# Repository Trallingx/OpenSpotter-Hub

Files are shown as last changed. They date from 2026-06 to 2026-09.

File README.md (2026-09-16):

# OpenSpotter Hub

OpenSpotter Hub is an open-source workspace for liquid-handling and spotting platforms. The repository currently contains one implemented platform, OpenSpotter-Syringe, together with its desktop control software, Klipper configuration, mechanical files, and engineering references.

## Platforms

- [OpenSpotter-Syringe](OpenSpotter-Syringe/README.md) is the active syringe-based spotting implementation.

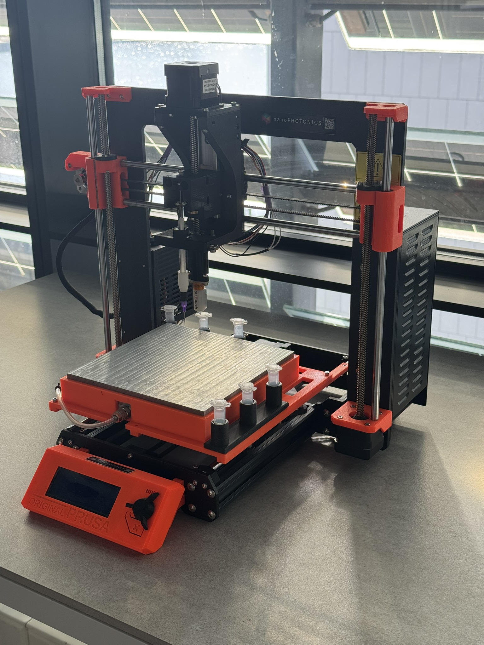
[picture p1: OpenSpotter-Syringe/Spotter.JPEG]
OpenSpotter-Syringe V1 hardware


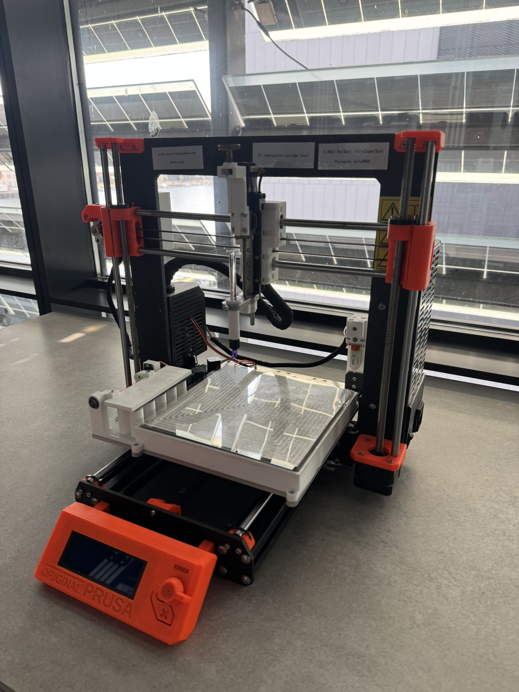
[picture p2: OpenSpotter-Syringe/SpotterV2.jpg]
OpenSpotter-Syringe V2 hardware


- [OpenSpotter-JetValve](OpenSpotter-JetValve/README.md) no JetValve implementation is present yet.

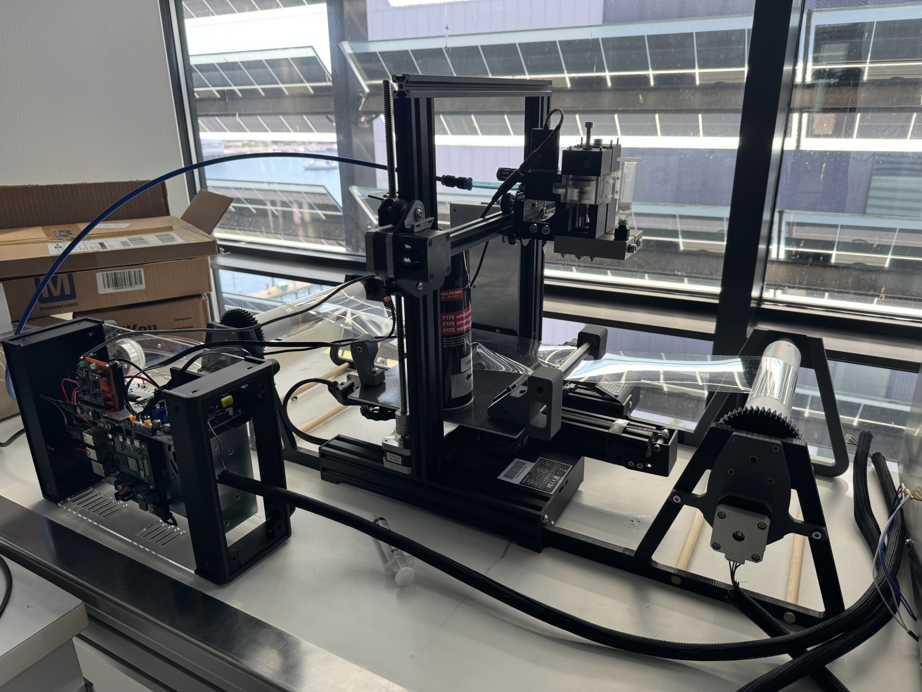
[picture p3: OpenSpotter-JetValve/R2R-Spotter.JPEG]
OpenSpotter-JetValve hardware


## Syringe project map

- [Getting started](OpenSpotter-Syringe/GETTING_STARTED.md)
- [Project scope](OpenSpotter-Syringe/PROJECT_DESCRIPTION.md)
- [Control application](OpenSpotter-Syringe/Spotter-Control_v3/README.md)
- [Klipper configuration](OpenSpotter-Syringe/Spotter-Control_v3/hardware/klipper/README.md)
- [CAD files](OpenSpotter-Syringe/CAD/README.md)
- [Engineering documents](OpenSpotter-Syringe/Docs/README.md)
- [Complete documentation index](OpenSpotter-Syringe/DOCS_INDEX.md)

## Safety and maturity

This is research hardware, not a validated medical or production system. Verify wiring, travel limits, tool state, calibration, generated G-code, and fluid compatibility on the physical machine before enabling motion or dispensing. The included Klipper configuration targets an Einsy RAMBo 1.1a and must be reviewed for the actual build.

The repository is licensed under the [MIT License](LICENSE.txt). Retain any additional file-level notices attached to adapted third-party material.

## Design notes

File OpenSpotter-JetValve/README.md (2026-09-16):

# Klipper OpenSource Spotter

Desktop GUI for drop-on-demand spotting with Klipper and Moonraker.

## Overview

Klipper OpenSource Spotter is a PyQt6 application that provides:
- valve control and macro execution
- 2D spotting canvas, live toolhead marker, and grid workflow
- status/logging and machine configuration panels
- Moonraker connectivity for motion and command execution

## Current Capabilities

- PyQt6 desktop UI with panels for machine status, controls, canvas, grid setup, valve config, and macro execution.
- Moonraker REST and WebSocket communication for connection status, G-code dispatch, subscribed toolhead position updates, and raw console responses.
- Top-bar Pi file editor for Moonraker-exposed config files and scripts, with save-to-Pi, save-and-restart, service status/actions, and a local Windows-to-Pi sync prompt for checked-in Pi-target files.
- Hardware-only spotting through the unified Klipper `SHOOT` macro; the current valve timing path preloads a Pi-connected Arduino over USB and triggers valve 0 or valve 1 with Pi host-MCU GPIO edges.
- Grid-based spotting with per-grid valve selection, per-grid speed, editable grid names, active/inactive grid toggles, and canvas redraws on grid changes.
- The canvas shows the latest toolhead position as a black X using the live gantry position signal.
- Roll-to-roll canvas mode renders two anchored rows per active grid and a compact row-progress legend instead of drawing every configured Y row.
- The spotting backend uses a row-indexed virtual spot sequence, windowed position projection, and bounded R2R progress payloads so large row counts do not allocate a full spot/path cache.
- Grid definitions are edited in the main window grid panel, not in the machine configuration dialog.
- Bounded spotting dispatch with editable Klipper send-ahead and refill-threshold settings, so a run tops the in-flight queue back up to the configured window after the configured number of spots completes.
- Active Stop and app shutdown are soft stops: the GUI stops refilling Klipper and clears pending local dispatch scripts without putting Klipper into shutdown.
- Configurable start and end G-code scripts stored in `config/machine_config.json`.
- User-facing actions and Moonraker traffic logged to `logs/dod_system.log`, trimmed in batches toward the newest 1000 lines so logging does not block high-rate spotting.

## Current Constraints

- Camera service and camera controller are placeholder-level.
- Calibration manager support is removed for now; only calibration data models remain.
- Test coverage is still limited, but includes model, macro command, spotting dispatch, and logging regressions.
- Hardware behavior should be validated against Moonraker/Klipper logs before changing motion or valve timing assumptions.

## Run

1. Create and activate a virtual environment.
2. Install dependencies.
3. Run the app.

```bash
pip install -r requirements.txt
python main.py
```

## Test

```bash
pytest tests/ -v
```

On the checked-in Windows development environment, use the virtualenv directly if `pytest` is not on PATH:

```powershell
.\.venv\Scripts\python.exe -m pytest tests/ -v
```

## Project Layout

- [models](models): data models
- [views](views): UI widgets and panels
- [controllers](controllers): orchestration and feature logic
- [services](services): Moonraker, camera, logging integrations
- [utils](utils): config, helpers, signals
- [docs](docs): hardware and integration documentation

## Documentation

- [DOCS_INDEX.md](DOCS_INDEX.md): documentation map
- [GETTING_STARTED.md](GETTING_STARTED.md): developer onboarding
- [PROJECT_DESCRIPTION.md](PROJECT_DESCRIPTION.md): concise project spec
- [AGENTS.md](AGENTS.md): mandatory Codex and contributor workflow rules
- [docs/START_TO_FINISH_FLOW.md](docs/START_TO_FINISH_FLOW.md): simple walk-through of the Start button to job completion
- [docs/PI_CR6_CONNECTION.md](docs/PI_CR6_CONNECTION.md): Pi + CR6 setup
- [docs/ARDUINO_VALVE_BRIDGE.md](docs/ARDUINO_VALVE_BRIDGE.md): Pi USB Arduino valve timing bridge
- [docs/TROUBLESHOOT_CONNECTION.md](docs/TROUBLESHOOT_CONNECTION.md): connection troubleshooting

## Contribution Rule

Read [AGENTS.md](AGENTS.md) before making changes. When behavior, architecture, commands, configuration, or setup steps change, update the relevant documentation and AGENTS change log in the same change.

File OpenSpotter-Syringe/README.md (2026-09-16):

# OpenSpotter-Syringe

OpenSpotter-Syringe is an open-source, syringe-driven liquid-handling and spotting platform. It combines a Python/Tkinter experiment editor, reproducible G-code generation, Klipper configuration for an Einsy RAMBo 1.1a, and two generations of mechanical design files.

SyringeSpotterV2 Hardware
OpenSpotter-Syringe hardware
GCODE creation GUI with Realtime Controls
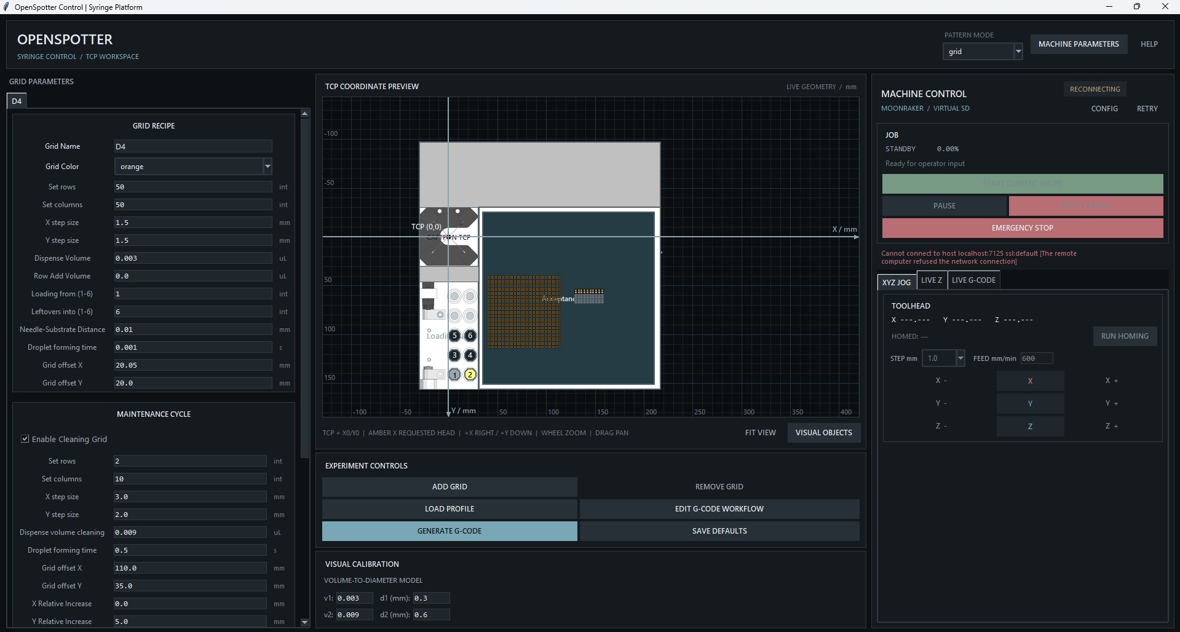
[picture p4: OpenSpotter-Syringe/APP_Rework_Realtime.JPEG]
OpenSpotter-Syringe hardware


# DEV NOTE
  The current capabilities (V2) are not 100% tested and a full test has not been run yet! The Spotter is not operational prior to software updates. The current version stops prior to bed meshing because of safety interlocks. This could be bypassed, but needs a proper check with test syringe (not glass !!!) before allowing moves. 

  The TCP finds the relative z position of the needle tip and the 3D-Touch creates a bed mesh to account for bed variations, but the offset between TCP-X-BEAM (trigger) and surface has not been measured yet. This will be a absolut offset that applies to all needles, even if mounted at different heights, but has to be manually checked once. RUN TCP calibration, RUN bed mesh, move needle to needle offset, move down to substrate (final accuracy z 20 micron), note offset. 

  Spiral mode is experimental and GCODE creation has not been veryfied. NOT operational!

## Current capabilities

- Configure multiple droplet grids, cleaning and washing cycles, final rinses, and spiral paths.
- Preview geometry in millimetres around the CAPTRON TCP beam crossing at X0/Y0.
- Edit Start, Loading, Printing, Cleaning, and End G-code event blocks at runtime.
- Save versioned JSON profiles beside generated G-code and load those profiles back into the application.
- Connect directly to Moonraker for exact virtual-SD upload/start, monitored Pause/Resume/Cancel, independent Emergency Stop, guarded XYZ motion, and live needle Z trim.
- Calibrate a needle TCP with the retained Klipper optical-cross module.
- Apply saved TCP offsets, bed mesh compensation, and a live needle-to-surface Z trim.
- Use a neutral graphite scientific UI defined centrally in `app/ui_theme.py`.

## Start here

- [GETTING_STARTED.md](GETTING_STARTED.md): install, validate, generate a job, and prepare hardware.
- [Spotter-Control_v3/README.md](Spotter-Control_v3/README.md): application behavior and profile contract.
- [Spotter-Control_v3/ARCHITECTURE.md](Spotter-Control_v3/ARCHITECTURE.md): deployable core/plugin architecture and dependency boundaries.
- [Spotter-Control_v3/PLUGIN_DEVELOPMENT.md](Spotter-Control_v3/PLUGIN_DEVELOPMENT.md): external pattern plugin contract and examples.
- [Spotter-Control_v3/DEPLOYMENT.md](Spotter-Control_v3/DEPLOYMENT.md): wheel, standalone, and writable-data deployment.
- [Spotter-Control_v3/hardware/klipper/README.md](Spotter-Control_v3/hardware/klipper/README.md): configuration, commissioning, TCP calibration, and movement safety.
- [CAD/README.md](CAD/README.md): mechanical-file inventory and manufacturing cautions.
- [Docs/README.md](Docs/README.md): BOM, schematics, datasheets, calibration references, and photos.
- [DOCS_INDEX.md](DOCS_INDEX.md): complete documentation map.

Generated files default to `Spotter-Control_v3/output/gcodes`. That directory is intentionally ignored except for `.gitkeep`; it contains runtime output, not maintained examples.

## Repository layout

- `Spotter-Control_v3/app/core`: reusable plugin, schema, storage, canvas,
  workflow, and shared G-code services.
- `Spotter-Control_v3/app/plugins`: built-in grid and spiral pattern packages;
  installed patterns use the documented entry-point contract.
- `Spotter-Control_v3/app`: generic desktop shell, compiled workflow renderer,
  direct-run artifacts, and Moonraker runtime/controller.
- `Spotter-Control_v3/config`: editable JSON defaults, workflow, visual layout, and UI state.
- `Spotter-Control_v3/hardware/klipper`: active Klipper configuration and custom TCP module.
- `Spotter-Control_v3/tests`: standard-library unit and integration tests.
- `CAD`: native design files and manufacturing exports.
- `Docs`: component and calibration references.

## Project status

Software generation and fake-Moonraker control paths have unit/integration coverage. Physical commissioning, hardware-in-the-loop validation, and experiment-specific risk assessment remain operator responsibilities. Computer vision, automatic lid handling, and a JetValve controller are not implemented in this repository.

Related publication: [ACS Sensors, DOI 10.1021/acssensors.5c02007](https://pubs.acs.org/doi/10.1021/acssensors.5c02007).

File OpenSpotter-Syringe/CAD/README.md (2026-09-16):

# OpenSpotter-Syringe CAD

The CAD directory contains two design generations:

- `Syringe_Spotter_V1`: 77 native `.prt` files.
- `Syringe_Spotter_V2`: 121 native `.prt` files plus selected manufacturing exports.

V2 exports include:

- `3D-Printing`: STL parts and one assembled 3MF package;
- `CNC-Mill`: machine-specific G-code exports;
- `Waterjetting`: DXF geometry with OMX, PDF, and log companions.

The folder names indicate design generations, not a formal released-build status. There is no authoritative release manifest identifying which duplicate or suffixed file is approved for a particular machine.

## Before manufacturing

1. Confirm the intended physical revision against the [BOM](../Docs/BOM.xlsx), drawings, and existing machine.
2. Open the native assembly and check dependencies, units, coordinate systems, clearances, and hardware.
3. Verify material, thickness, tolerances, orientation, and process parameters independently.
4. Regenerate CNC or waterjet toolpaths for the actual machine, stock, tooling, and controller. Checked-in G-code/OMX files are references, not universally safe jobs.
5. Inspect printable exports for scale, manifold geometry, supports, and fit before producing a full set.

For the TCP sensor and detachable-probe context, see the [engineering document index](../Docs/README.md) and [Klipper hardware guide](../Spotter-Control_v3/hardware/klipper/README.md).

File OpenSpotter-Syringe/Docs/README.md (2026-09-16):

# Engineering Documents

This directory collects component, electronics, and calibration references for OpenSpotter-Syringe. A file's presence does not prove that its revision matches every physical build; confirm part numbers, wiring, dimensions, and ratings before use.

## Build and electronics

- [Bill of materials](BOM.xlsx)
- [Einsy RAMBo 1.1a schematic](<Schematic Prints_Einsy Rambo_1.1a.PDF>)
- [LMD8S12BSS05-060 actuator datasheet](LMD8S12BSS05-060_Full_Datasheet.pdf)

The checked-in Klipper configuration targets the Einsy RAMBo 1.1a. Pin assignments and electrical limits still require comparison with the actual board and connected hardware.

## CAPTRON optical TCP

- [CAPTRON application note](CAPTRON_Application_Note_TCP.pdf)
- [CAPTRON optical-sensor catalog](CAPTRON-Optical-Sensors-Catalog.pdf)
- [OGLW2-40T-2PS6 datasheet](OGLW2-40T-2PS6-DS_V1.1_de_en.pdf)
- [OGLW2-70T4-2PS6 datasheet](OGLW2-70T4-2PS6-DS_V1.0_de_en.pdf)
- [TCP photo 1](TCP_1.jpg), [photo 2](TCP_2.jpg), [photo 3](TCP_3.jpg), [photo 4](TCP_4.jpg)

The active Klipper config names the OGLW2-40T-2PS6 and uses active-low NPN inputs. The 70T4 document remains a design/component reference.

## Calibration and coordinate stack

- [Needle, bed-mesh, TCP, and live-offset stack](needle-bed-mesh-tcp-offset-stack.pdf)
- [TCP calibration algorithm flow](../Spotter-Control_v3/hardware/klipper/config/scripts/tcp_calibration_flow.pdf)
- [Klipper commissioning guide](../Spotter-Control_v3/hardware/klipper/README.md)

## External references

- [Official Klipper documentation](https://www.klipper3d.org/)
- [Einsy RAMBo overview](https://reprap.org/wiki/EinsyRambo)
- [Einsy RAMBo development notes](https://reprap.org/wiki/EinsyRambo_development)

The repository's current host-side configuration is Moonraker/Mainsail-oriented. Use the checked-in configuration and hardware guide as the project source of truth.

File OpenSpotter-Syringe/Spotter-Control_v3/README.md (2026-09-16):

# Spotter-Control_v3

Spotter-Control_v3 is the local desktop recipe editor, G-code generator, and Moonraker machine console for OpenSpotter-Syringe. It uses Tkinter, Pillow, and a persistent aiohttp WebSocket/HTTP client. Saved-file generation remains available without a printer connection.

## Run

From this directory on Windows PowerShell:

```powershell
python -m venv .venv
.\.venv\Scripts\Activate.ps1
python -m pip install --upgrade pip
python -m pip install -e .
openspotter-control
```

On macOS or Linux:

```sh
python3 -m venv .venv
source .venv/bin/activate
python -m pip install --upgrade pip
python -m pip install -e .
openspotter-control
```

`python main.py` and `python -m app` remain equivalent source launchers. See
[DEPLOYMENT.md](DEPLOYMENT.md) for wheels, standalone builds, writable runtime
locations, and migration from an older checkout.

## Validate

```powershell
python -m pip install -e ".[test]"
python -m compileall -q app
python -m unittest discover -s tests -v
```

Launch the GUI after changes to appearance, interaction, paths, images, or workflow editing.

## Runtime logs

Each application run writes `openspotter-control.log` under the active runtime
root's `logs` directory. Source checkouts keep the historical local path;
installed and frozen builds use per-user writable storage. The file records
startup state, effective global and recipe options, workflow/profile changes,
generation choices, output paths, fallback defaults, and failures. Logs rotate
at 5 MB with five backups, and credential-like values are redacted.

The default level is `INFO`. Set `OPENSPOTTER_LOG_LEVEL=DEBUG` before launching to include detailed workflow-trigger decisions:

```powershell
$env:OPENSPOTTER_LOG_LEVEL = "DEBUG"
python main.py
```

## Interface

The interface uses a low-saturation graphite scientific palette, restrained steel-blue accents, semantic status colors, Segoe UI text, and Consolas for machine-oriented text. All shared colors, fonts, classic Tk options, and ttk styles live in `app/ui_theme.py`.

The main workspace provides:

- global machine parameters in a persistent maximized editor opened beside **HELP**;
- multiple grid recipes with optional cleaning, washing, and final-rinse behavior;
- multiple spiral recipes;
- a TCP-relative geometry preview;
- JSON profile loading;
- a runtime G-code workflow editor;
- atomic plugin-driven G-code generation (grid and spiral are built in);
- Moonraker connection state, virtual-SD Start/Pause/Resume/Cancel, HTTP emergency stop, guarded XYZ jog, an operator-owned `HOMING` action, live needle Z trim, and a read/queued G-code cursor.

## Persisted data

| Data | Location | Behavior |
| --- | --- | --- |
| Global and recipe defaults | `config/config_*.json` | Loaded at startup and updated through **SAVE DEFAULTS**. |
| Pattern counts | `config/config_states.json` | Schema-version 2 registered-plugin counts, with legacy built-in keys accepted. |
| Active workflow | `config/config_gcode_workflow.json` | Validated and saved explicitly in the workflow editor. |
| Preview objects and links | `config/config_visual_objects.json` | Saved independently; geometry never feeds the planner directly. |
| Moonraker example | `config/config_moonraker.example.json` | Key-free connection example. |
| Local Moonraker settings | `config/config_moonraker.json` | Created by **CONFIG**, ignored by Git, and may contain an API key. |
| Job snapshot | `*_settings.json` beside output | Reproducible schema-version 3 plugin profile with legacy built-in arrays. |

## Generate G-code

Select **GENERATE G-CODE** after adding at least one pattern recipe. The chosen path is a base path:

- every non-empty application plugin produces `<base>_<plugin-id>.gcode`;
- the built-in examples are `<base>_grid.gcode` and
  `<base>_spiral.gcode`;
- when several plugin workspaces contain recipes, each produces its own file;
- every G-code file receives a matching `<job>_settings.json` sidecar.

Profiles contain global settings, the recipes for that job type, derived runtime values, and the exact effective workflow. Writes are atomic. The dialog starts in `output/gcodes`; this directory is ignored runtime storage and contains no maintained examples.

**LOAD PROFILE** accepts JSON profiles only. Loading a profile:

1. validates the document structure;
2. replaces all registered pattern workspaces with the saved recipes;
3. restores global values;
4. if `workflow` is present, validates it and overwrites the active `config/config_gcode_workflow.json`.

Treat profile loading as a workflow change, not only a form import.

## Direct Moonraker control

The right-side machine panel starts a background Moonraker runtime without blocking Tk. **CONFIG** edits the host, port, protocol, route prefix, and optional API key; **RETRY** restarts monitoring. The WebSocket is persistent, identified as a desktop client, and subscribes to printer, virtual-SD, position, prompt, saved calibration, and live-Z state. Commands queued before connection or lost before sending fail instead of replaying after reconnect. On a Pi Zero, a fixed IPv4 address can avoid Windows `.local`/mDNS lookup delays.

Deploy the current `hardware/klipper/config/hardware.cfg`, `remote_control.cfg`, and `movement_safety.cfg` together, keep the current `config/config_gcode_workflow.json`, preserve the operator-owned Klipper configuration that defines `HOMING`, and restart Klipper. The app checks Klipper's advertised commands for the immutable `OPENSPOTTER_CONTRACT_V4` marker and the single required homing macro `HOMING`. Start, Home, jog, and related machine controls remain disabled when that contract is missing or stale.

**START CURRENT RECIPE** follows this contract:

1. require locked machine parameters and a connected, ready, idle Klippy state;
2. ask the selected plugin to capture immutable recipes on the Tk thread;
3. reject invalid text, unbounded pattern/maintenance work, or non-finite inputs;
4. generate and hash the exact artifact in a worker, using compiled workflow expressions;
5. compare rendered XYZ targets plus saved TCP/live-Z offsets with live axis limits;
6. require a loaded BLTouch when the artifact uses `MESH`, and valid TCP coordinate version 2 when it enables needle offsets;
7. show the artifact hash, workflow hash, size, line count, destination, and physical-action warning for final operator confirmation;
8. upload with `print=false`, run a fresh ready/idle preflight, and send one `printer.print.start` RPC.

The separate upload/start sequence deliberately avoids Moonraker’s optional upload queue, which could otherwise schedule motion for later. Repeated identical artifacts use the same SHA-256 remote filename under `gcodes/openspotter/<kind>/`; local runtime output retains the newest 20 artifacts per kind.

Pause/Resume and Stop control the active virtual-SD job. Stop invokes Klipper cancellation and the non-motion `OPENSPOTTER_JOB_CLEANUP` macro. **EMERGENCY STOP** bypasses the WebSocket command queue and posts directly to Moonraker’s authenticated `/printer/emergency_stop` endpoint with a short timeout.

XYZ jog is available only while connected, ready, idle, inactive in virtual SD, and homed on all axes, with needle offsets disabled and bed mesh cleared. It calls the reviewed `OPENSPOTTER_JOG` firmware macro, which requires at least 30 mm/min and validates finite distance/feed values, axis-specific limits, physical toolhead bounds, and movement dead zones.

The UI Home action issues exactly one bare `HOMING` command, and the default workflow also contains exactly one bare `HOMING` command. The application does not define or inspect that macro's physical choreography. Define and commission it in operator-owned Klipper configuration outside `remote_control.cfg`.

The V4 interface requires `HOMING` to be safe both when called from the idle UI and when called at the start of an active virtual-SD job. Before its first move it must either neutralize needle offsets and bed mesh or reject the call, it must preserve and restore relevant modal G-code state, and it must return with XYZ homed. Make `M400` its final executable command so all queued physical motion completes before the macro returns. `HOMING` is public to every authorized Moonraker client, so the firmware macro itself—not only this application's UI checks—must validate its preconditions.

When a job artifact uses `MESH`, Start preflight already requires the saved BLTouch state to be `loaded`; the operator must also verify the tool physically before Start. `HOMING` is not relied upon to load or park the BLTouch.

Live Z calls the transactional needle-offset macros only during an active job while offsets are enabled. Negative values move closer to the substrate; positive values move away. UI adjustments are live (`SAVE=0`) and are not persisted automatically.

The canvas adds an amber **LIVE REQUESTED TOOLHEAD** cross when Moonraker has supplied fresh position data for homed X/Y axes. It shows Klipper's requested trajectory in raw carriage coordinates rather than encoder feedback, and is intentionally separate from the logical needle-tip path when TCP offsets are enabled. The marker is hidden on disconnect, Klippy restart, stale telemetry, or unhomed X/Y, and it follows pan/zoom without refitting the workspace.

The G-code tab shows Moonraker’s `virtual_sdcard.file_position` mapped onto the exact local artifact. It is explicitly a virtual-SD read/queued cursor, not proof that physical motion has completed. The view is hidden if another filename is active. A response timeout or post-send disconnect is treated as an unknown printer-side outcome; normal controls remain interlocked until monitoring is reconnected, while Emergency Stop stays available.

**MANUAL / CONSOLE** parses text before it can be sent. It accepts a small diagnostic allowlist plus `G90`, `G91`, and bounded `G0`/`G1` XYZ/F moves. Raw motion requires an explicit coordinate mode and feed in the same script, Klipper-native plain decimal words (no `=` or scientific notation), live bounds, homed XYZ, offsets and bed mesh off, no virtual-SD activity, a 30–6000 mm/min feed, and an estimated total duration no longer than 60 seconds. The operator-owned `HOMING` macro is accepted only as a standalone action; unknown macros, raw `G28` homing, arcs, output/driver changes, safety mutations, and other bypass commands are blocked. `M112`/`EMERGENCY_STOP` is routed through Moonraker's HTTP emergency-stop endpoint rather than the queued G-code path. A partial script error, missing completion sentinel, E-stop, timeout, or disconnect latches the machine controls until the operator inspects the printer and reconnects monitoring.

Preflight is not a complete interpreter for arbitrary custom macros or raw G-code. Review the exact artifact and perform an elevated, fluid-free dry run after changing workflows, profiles, fixtures, or firmware. The supplied Moonraker configuration permits unauthenticated clients from IPv4 private and link-local networks so any local PC can use Mainsail or OpenSpotter; keep port 7125 off the public Internet.

## Runtime G-code workflow

**EDIT G-CODE WORKFLOW** opens the editor for ordered Start, Loading, Printing, Cleaning, and End blocks. Sections attach templates and optional conditions to planner events. The editor supports validation, rendered previews, searchable scoped variables, and custom-variable expressions.

The editor opens maximized in normal windowed mode. Its workspace and preview area share a vertical page scrollbar, while the header, status, and Save/Cancel controls remain visible.

The Python planner retains numeric state and the physical lifecycle: start, refill, pattern motion, maintenance, emptying, and end. Workflow blocks are event hooks; reordering them changes template order for a matching event but does not replace the planner.

Variables are namespaced by global, grid, cleaning, washing, spiral, container, runtime, or custom scope. Grid-only and spiral-only values on shared events should be guarded with a condition such as `runtime.job.kind == 'grid'`. `custom.syringe_mm_per_ul` and `custom.spiral_resolution_radians` are required planner inputs and must remain positive.

Grid and spiral are the shipped pattern plugins. Compatible installed plugins
may add workspaces, workflow events, canvas previews, saved generation, and
direct-run capture/generation through plugin API 1. Startup needle calibration
and hardware TCP calibration remain separate safety workflows.

## TCP coordinate preview

The CAPTRON beam crossing is visual X0/Y0. Positive X is right and positive Y is down, matching the configured machine motion from the TCP toward the work area. Scroll zooms, dragging pans, and **FIT VIEW** restores the useful extent.

**VISUAL OBJECTS** manages rectangles, circles, and images:

- rectangle X/Y identifies its top-left corner;
- circle X/Y identifies its centre;
- image X/Y identifies its top-left corner;
- width and height may differ, producing an oval;
- images are stretched to the exact width and height entered in millimetres;
- **IMPORT IMAGE…** starts in the project asset folder and can browse to any image path; select **APPLY CHANGES** to persist the draft;
- project-contained images are stored with portable relative paths, while external files use absolute paths;
- text size, descriptive text, and color are editable; image color controls its centred description text;
- rectangle and circle fills are solid;
- X, Y, width, and height can each be linked to a numeric program input by using the dropdown beside the value;
- the object list is a layer stack: higher rows draw above lower rows, and **MOVE UP** / **MOVE DOWN** persist adjacent layer changes immediately.

The program input is authoritative while a property is linked. Changing that input moves or resizes every linked object on the next canvas refresh. Changing a linked value in **VISUAL OBJECTS** and selecting **APPLY CHANGES** writes the value back to the program input, so every other object using the same link follows it. Locked global machine parameters cannot be changed through the visual editor; unlock them through the normal safety control first. Visual links are saved immediately, while changed program values use the existing **SAVE DEFAULTS** action for persistence.

The editable layout starts with the former canvas overlays: build plate, acceptance area, six containers, and the CAPTRON TCP image. Legacy container circles automatically link X/Y to `global.containerN_x/y`, including existing schema-version 1 layouts, so the visual container and loading coordinate remain coupled. Other stable choices include indexed grid, cleaning, washing, and spiral inputs such as `grid.1.grid_offset_x`. The CAPTRON object uses `assets/Captron-TCP.png` and defaults to exactly 60 × 60 mm at X=-30..30 and Y=-30..30.

Unlinked object values remain annotations and never enter generated commands, homing, firmware limits, acceptance checks, or Klipper configuration. A linked visual edit can affect generation only by updating its real program input; visual-object geometry itself is still excluded from the planner. Missing or temporarily invalid link sources use the object's stored fallback value. The coordinate grid, TCP origin marker, generated grid/spiral points, cleaning previews, and washing lines remain live preview primitives rather than editable layout objects. The preview and its acceptance warning are planning aids, not collision protection.

## Hardware boundary

The supplied application workflow disables needle offsets before `HOMING` and `MESH`, then enables them after `MESH`, and disables them at job end. When enabled, the Klipper wrapper applies:

```text
machine X = commanded X + tcp_offset_x
machine Y = commanded Y + tcp_offset_y
machine Z = commanded Z + tcp_offset_z + needle_surface_z_offset
```

Relative moves remain deltas and Klipper bed mesh remains active independently. This behavior is editable through the workflow, so inspect the effective profile rather than assuming the shipped defaults.

TCP calibration now records coordinate version 2. Saved offsets from the former positive-up Y convention are rejected until calibration is run again.

The workflow does not run `TCPSTART` and does not automatically load or park the detachable BLTouch. Direct Start checks the saved readiness state but cannot verify physical tool attachment. Deploy the complete matching hardware/remote-control/safety configuration, restart Klipper, and follow the [Klipper hardware guide](hardware/klipper/README.md) before any machine run.

## Layout

- `main.py`: stable launcher.
- `app/core`: reusable contracts and services for plugins, schemas, storage,
  canvas previews, workflow composition, and shared G-code lifecycle.
- `app/plugins`: built-in grid and spiral pattern packages.
- `app`: generic Tk shell, compiled workflow renderer, runtime artifacts, and
  Moonraker runtime/controller.
- `config`: defaults and persisted application state.
- `assets/images`: current static GUI images.
- `tests`: planner, workflow, generation, visual-object, and hardware-config checks.
- `hardware/klipper`: active printer configuration and custom TCP module.
- `output/gcodes`: ignored runtime output.
- [DEPLOYMENT.md](DEPLOYMENT.md): source, wheel, standalone, and runtime-data deployment.
- [VERSIONING.md](VERSIONING.md): application, schema, and firmware compatibility versions.
- [CHANGELOG.md](CHANGELOG.md): user-visible release history.
- [ARCHITECTURE.md](ARCHITECTURE.md): core/plugin boundaries, runtime layers,
  dependency rules, and migration status.
- [PLUGIN_DEVELOPMENT.md](PLUGIN_DEVELOPMENT.md): installed entry points and
  desktop plugin hooks.
- [Spotter_Control_Dev.md](Spotter_Control_Dev.md): source-level developer map.

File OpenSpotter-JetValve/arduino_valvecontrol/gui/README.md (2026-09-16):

# Arduino Timing GUI

PyQt5 desktop app to control the ON/OFF timings on the Arduino via the serial protocol implemented in `main.cpp`.

## Setup

1. Install Python 3.10+.
2. In this folder, install deps:
   ```bash
   pip install -r requirements.txt
   ```
3. Run the app:
   ```bash
   python app.py
   ```

## Firmware protocol (implemented in main.cpp)
- `?` or `W` — request current state.
- `S:onMin:onMax:offMin:offMax` — set ranges; step ≈ (max-min)/9.
- `O:<ms>` — set ON time directly.
- `P:<ms>` — set OFF time directly.
- `E` / `R` — ON minus/plus one step.
- `D` / `F` — OFF minus/plus one step.
- `T` — toggle run/stop (output forced LOW when stopped).
- State line format: `STATE on=<ms> off=<ms> onRange=<lo>-<hi> offRange=<lo>-<hi> running=0|1`.

## GUI controls
- Port selector → Connect.
- Checkbox "Running" toggles `T`.
- ON row: min/max fields, slider, value label, buttons "ON - (E)" / "ON + (R)" (keyboard E/R).
- OFF row: same pattern with D/F.
- Sliders and buttons snap to the step implied by current ranges.

## Notes
- The app polls serial every 50 ms and debounces slider/range changes.
- If the port drops, the app will disconnect and show an error in the status label.

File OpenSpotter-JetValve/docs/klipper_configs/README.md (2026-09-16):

# Klipper Config Snippets

Reusable Pi/CR6 snippets for the current GUI integration.

## Files

- `printer.cfg`: top-level include template
- `steppers.cfg`: CR6 axes plus `r2r_rewind` manual stepper helpers
- `valve_macros.cfg`: Arduino bridge, valve timing preload, and `SHOOT`
- `moonraker.conf`: Moonraker sample
- `mainsail.cfg`: Mainsail macro sample
- `sonar.conf`: optional network watchdog sample

Legacy LED and safety snippets were removed; keep new setup steps aligned with the files listed above.

## Valve Path

- Continuous spotting uses `SET_ARDUINO_VALVE_TIMING` once per active valve, then per-spot `SHOOT ... TRIGGER_MODE=mcu`.
- Current Arduino firmware is pulse-only. `HOLD`, latched `VALVE_ON`, and latched `VALVE_OFF` are unsupported.
- MCU-mode per-spot `SHOOT` omits `ON_MS`, `OFF_MS`, and `CYCLES`; those values come from the preload.
- USB fallback can still send `ON_MS`, `OFF_MS`, and `CYCLES` for manual testing.

## Start And End G-code

The GUI stores free-form scripts in `config/machine_config.json`:

- `klipper.start_gcode`: runs before spotting homing validation.
- `klipper.end_gcode`: runs after spotting finishes or stops.
- `klipper.connect_gcode`: runs once after Moonraker connects.

Enter one G-code command per line. Blank lines are ignored.

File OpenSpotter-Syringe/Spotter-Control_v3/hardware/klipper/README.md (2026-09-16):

# OpenSpotter Klipper Configuration

This directory contains the active Klipper configuration template for the OpenSpotter-Syringe build. It targets an Einsy RAMBo 1.1a with TMC2130 drivers, a manual syringe stepper, a detachable BLTouch-compatible probe, and a CAPTRON optical TCP cross.

It is not a universal or automatically safe configuration. Pins, axis directions, sensorless-homing thresholds, travel limits, dock coordinates, optical geometry, and syringe direction must be verified on the physical machine.

## Active files

`config/printer.cfg` is the include root:

| File | Responsibility |
| --- | --- |
| `hardware.cfg` | X/Y/Z pins, ranges, homing, and servo |
| `tmc2130.cfg` | All X/Y/Z/syringe TMC2130 sections |
| `syringe.cfg` | Manual syringe stepper and dispense/aspirate macros |
| `bltouch.cfg` | Probe pins, detachable dock macros, and saved-state initializer |
| `movement_safety.cfg` | G0/G1 wrappers, TCP/live-Z offsets, and persistent dead zones |
| `bed_mesh.cfg` | Bed mesh and `MESH`, `MESH_LOAD`, `MESH_CLEAR` macros |
| `display.cfg` | 20 × 4 LCD content |
| `mainsail.cfg` | Minimal virtual-SD, pause, resume, cancel, display, and respond support |
| `remote_control.cfg` | Guarded desktop jog support, contract marker, structured prompts, and job cleanup |
| `tcp_calibration.cfg` | Optical sensor power, macros, pins, and module settings |

`config/moonraker.conf` configures the separate Moonraker service and is not included by Klipper. `config/saved_vars.cfg` is a repository seed with only the initial syringe position; calibration and runtime values are machine-specific.

The repository does not vendor Klipper. The canonical custom module is `config/scripts/tcp_calibration.py`.

## Deployment

Back up the printer's existing configuration and Klipper source before replacing anything.

1. Copy the contents of `config` into the printer's configuration directory, normally `~/printer_data/config`.
2. Install the custom TCP module as described in [config/scripts/README.md](config/scripts/README.md).
3. Review the MCU serial path in `printer.cfg`, the virtual-SD path in `mainsail.cfg`, and any Moonraker paths for the actual host.
4. Compare every pin and connector with the supplied [Einsy RAMBo 1.1a schematic](../../../Docs/Schematic%20Prints_Einsy%20Rambo_1.1a.PDF).
5. Restart Klipper and resolve configuration errors before energizing motion.
6. Commission one subsystem at a time with the tool clear, low current/speed where practical, and an accessible emergency stop.

Do not deploy `remote_control.cfg` alone. At minimum, copy the current `hardware.cfg`, `movement_safety.cfg`, and `remote_control.cfg` together, keep the desktop's current `config/config_gcode_workflow.json`, preserve the operator-owned configuration that defines `HOMING`, and restart Klipper before using Start, jog, Home, prompt, or cleanup controls. The desktop requires the immutable `OPENSPOTTER_CONTRACT_V4` marker and the `HOMING` command; machine controls remain disabled if Klipper advertises a missing or stale contract.

In the desktop **CONFIG** window, enter the Moonraker host, port, protocol, optional route prefix, and API key. Local `config/config_moonraker.json` is ignored by Git; keep credentials out of the key-free example. A fixed IPv4 address may connect more quickly and reliably than `.local` on a Pi Zero/Windows mDNS combination.

The shipped `moonraker.conf` trusts localhost plus all IPv4 private and link-local client ranges, allowing Mainsail and OpenSpotter to connect from any PC on the local/private network without an API key. Public Internet addresses are not trusted. Keep the printer network isolated and do not expose TCP port 7125 through router port forwarding.

Do not copy calibrated `saved_vars.cfg` values from another machine.

## Commissioning checks

Before a job:

- confirm X/Z direction, and confirm positive Y moves from the TCP toward the work area (down in the top view);
- commission the operator-owned `HOMING` macro in both idle and active virtual-SD job-start contexts with fixtures and tools clear, verify each axis/endstop behavior at reduced risk, and make `M400` its final executable command;
- verify the syringe endstop, plunger direction, and volume conversion without fluid;
- verify BLTouch pin behavior and dock coordinates at reduced risk;
- test TCP power and both beam inputs;
- calibrate TCP and inspect the saved offsets;
- define and test fixture dead zones;
- confirm `OPENSPOTTER_CONTRACT_V4`, `HOMING`, `OPENSPOTTER_JOG`, `OPENSPOTTER_RUNTIME_STATUS`, and `NEEDLE_TIP_OFFSETS_STATUS` are recognized;
- confirm Moonraker exposes live toolhead limits, saved variables, the OpenSpotter runtime macro, and the needle-offset macro;
- run elevated, fluid-free G-code while watching machine coordinates.

The syringe coordinate model is E=0 at empty/fully depressed and E=50 mm at homed/full. `ASPIRATE` increases position toward 50; `DISPENSE` decreases it toward 0. Normal macro motion is clamped to that 0–50 mm working range, while the manual stepper's 70 mm `position_max` provides homing overtravel. Verify the real plunger direction, endstop location, and volume conversion before dispensing.

## Detachable BLTouch state

`LOAD_BLTOUCH` and `PARK_BLTOUCH` reject moves unless the saved state permits the requested transition. On a new `saved_vars.cfg`, state is unknown.

Physically inspect the probe first, then initialize the record:

```gcode
SET_BLTOUCH_DOCK_STATE STATE=parked
```

or:

```gcode
SET_BLTOUCH_DOCK_STATE STATE=loaded
```

This command does not move hardware. Use it only after physical verification. `TCPQUERYBLTOUCH` reports the state used by TCP guards.

The dock macros use raw `G0.1` moves so needle offsets are not applied. Those raw moves also bypass the normal G0 safety wrapper; verify dock coordinates and a clear path before use.

## Optical TCP calibration

The active-low NPN inputs are X on `PH0` and Y on `PK0`; sensor power is switched on `PE5`. The Python extra uses continuous homing-style moves rather than polling.

The active coordinate convention is positive X right and positive Y down in the machine top view. The reflected beam normals and `Y_DIRECTION=-1` keep the TCP scan on the same physical beam paths after the Y stepper direction inversion. Any machine calibrated under the previous Y convention must be homing-tested and TCP-calibrated again before saved needle offsets are enabled.

Calibration requires:

- all XYZ axes homed;
- saved BLTouch state `parked`;
- TCP power recorded on;
- a clear start position on the right/X+ side of the optical cross.

Test the inputs before motion:

```gcode
TCPON
TCPQUERYBEAMS
TCPOFF
```

With power on, query once clear and once while interrupting each beam by hand. `PRESSED` means that beam is disrupted.

For the normal guarded sequence, first disable needle corrections, run the commissioned `HOMING` macro, verify that it completed, and then run:

```gcode
TCPSTART X=<clear_start_x> Y=<clear_start_y> Z=<clear_start_z> HEIGHT=<beam_height> CALX=<nominal_cross_x> CALY=<nominal_cross_y> CALZ=<nominal_tip_z>
```

`X/Y/Z` position the clear start. `CALX/CALY/CALZ` are the expected final coordinates used to calculate offsets; if omitted they default to X/Y/Z. `TCPSTART` raises to `LIFTZ`, positions the tool, powers the sensor, calls the calibration module, then powers it off.

The module:

1. acquires the X beam with a pure-X move;
2. centres and follows that beam upward to the needle tip edge;
3. re-centres X at `tip_z - 2 mm`;
4. follows the physical X beam to centre Y in the same plane;
5. accepts the result only if stationary X and Y queries both report `PRESSED`.

Success saves `tcp_tip_x/y/z`, `tcp_offset_x/y/z`, `tcp_coordinate_version=2`, and `tcp_ready=True`. Needle-offset motion rejects older or unversioned calibrations. Inspect them with:

```gcode
TCPSHOWOFFSETS
NEEDLE_TIP_OFFSETS_STATUS
```

On a calibration fault, assume the TCP output may still need explicit cleanup and run `TCPABORT`; use `TCPABORT EMERGENCY=1` only when an emergency shutdown is required. The [TCP calibration flow diagram](config/scripts/tcp_calibration_flow.pdf) documents the routine.

## Needle offsets and bed mesh

Normal `G0` and `G1` are wrapped. With needle offsets enabled, absolute targets become:

```text
X machine target = X command + tcp_offset_x
Y machine target = Y command + tcp_offset_y
Z machine target = Z command + tcp_offset_z + needle_surface_z_offset
```

Relative moves remain unmodified deltas. Klipper applies the active bed mesh separately after the corrected target is sent.

Common commands:

```gcode
NEEDLE_TIP_OFFSETS_ENABLE
NEEDLE_TIP_OFFSETS_DISABLE
NEEDLE_TIP_OFFSETS_STATUS
SET_NEEDLE_SURFACE_OFFSET Z=-0.030 MOVE=1 SAVE=1
ADJUST_NEEDLE_SURFACE_OFFSET Z_ADJUST=0.005 MOVE=1
RESET_NEEDLE_SURFACE_OFFSET MOVE=1 SAVE=1
```

Enabling requires `tcp_ready=True` by default. `REQUIRE_TCP=0` exists for a controlled dry run and must not be used to imply a valid calibration.

The live surface trim defaults to a permitted range of -2 to +2 mm. Negative moves the needle closer to the substrate; positive moves it higher. `MOVE=1` applies the delta physically only while offsets are enabled, and `SAVE=1` persists it.

The shipped application workflow disables offsets before `HOMING` and `MESH`, enables them afterward, and disables them at job end. The workflow is editable and profiles embed the effective copy, so verify each job.

The application workflow does not call `TCPSTART` and does not automatically load or park the BLTouch. It assumes calibration and tool state have been prepared by the operator. Start preflight requires saved BLTouch state `loaded` before accepting an artifact that uses `MESH`, and the operator must verify the tool physically before Start; `HOMING` is not relied upon to load or park it.

The desktop direct-run preflight blocks an artifact containing `MESH` unless saved BLTouch state is `loaded`, and blocks needle-offset enablement unless `tcp_ready=True` with coordinate version 2. These are saved-state checks, not physical sensors: inspect the detachable tool and work area yourself.

Artifact preflight is deliberately conservative, but it is not a full Klipper G-code/macro interpreter. It checks rendered direct XYZ targets, current offsets, required saved tool state, and bounded work; custom workflow/profile commands may have additional effects. Review the exact confirmed artifact and run an elevated, fluid-free dry run after workflow, profile, fixture, or firmware changes.

## Desktop remote-control contract

The desktop uses the application-owned support commands below plus one operator-owned homing command:

```gcode
HOMING
OPENSPOTTER_JOG AXIS=X DISTANCE=1 F=600
OPENSPOTTER_RUNTIME_STATUS
OPENSPOTTER_JOB_CLEANUP
```

The UI Home action issues exactly one bare `HOMING` command, and the default workflow also contains exactly one bare `HOMING` command. `remote_control.cfg` intentionally does not define `HOMING`, and the application does not inspect or add to its physical choreography. Define and commission the macro in operator-owned Klipper configuration and keep that file outside `remote_control.cfg`.

The V4 interface requires `HOMING` to be safe in both supported call contexts: an idle UI request and the start of an already-active virtual-SD job. Before its first move the macro must neutralize needle offsets and bed mesh or reject the call, preserve and restore relevant modal G-code state, return with XYZ homed, and use `M400` as its final executable command. Because other authorized Moonraker clients can invoke the public macro without the OpenSpotter UI interlocks, `HOMING` itself must validate every precondition on which its safe execution depends.

`OPENSPOTTER_JOG` requires Klippy idle, inactive virtual SD, all XYZ axes homed, needle offsets disabled, and bed mesh cleared. It rejects non-finite/zero distance, limits XY to 25 mm and Z to 5 mm per command, requires at least 30 mm/min, caps XY feed at 6000 mm/min and Z feed at 1500 mm/min, checks live physical toolhead limits, and runs the dead-zone guard.

`OPENSPOTTER_JOB_CLEANUP` performs no motion. It disables needle offsets, clears bed-mesh compensation, clears the structured prompt/LCD message, and is called by normal completion, cancellation, and virtual-SD error handling.

The live needle-Z setter validates finite range/feed and the physical target, runs movement safety before changing coordinate mode, performs the compensation move, restores state, and only then commits or persists the new offset. Desktop adjustments use `SAVE=0`.

Desktop Emergency Stop bypasses the G-code/WebSocket command queue and sends a short-timeout authenticated HTTP POST directly to Moonraker `/printer/emergency_stop`.

The desktop manual console is intentionally not a general Klipper terminal. It permits a small diagnostic-query allowlist and bounded `G90`/`G91` plus `G0`/`G1` XYZ/F tests with explicit mode/feed, live bounds, homed XYZ, offsets/mesh off, no virtual-SD activity, and a 60-second estimated cap. The operator-owned `HOMING` macro is accepted only as a standalone action; unknown macros and commands that bypass homing, movement safety, offsets, drivers, outputs, or job preflight are blocked. Manual `M112` is routed to the same HTTP Emergency Stop. Partial execution errors or a missing completion response latch controls until the machine is inspected and monitoring is reconnected.

## Dead-zone guard

Movement safety is disabled by default unless a saved state enables it. Zones are persistent XY rectangles with a Z clearance and independent allowances for travel above the fixture, exit, pure Z lift/lower, or XY motion inside. The guard conservatively treats a move's XY bounding box as its swept area.

```gcode
SET_DEAD_ZONE NAME=fixture X_MIN=80 X_MAX=170 Y_MIN=60 Y_MAX=160 Z_CLEARANCE=20 ALLOW_WHEN_ABOVE=1 ALLOW_EXIT=1 ALLOW_Z_LIFT=1
MOVEMENT_SAFETY_ENABLE
MOVEMENT_SAFETY_STATUS
REMOVE_DEAD_ZONE NAME=fixture
CLEAR_DEAD_ZONES
```

Test every zone with controlled moves. `G0.1` and `G1.1` are the renamed raw Klipper moves; they bypass both correction and the normal guard and should remain limited to reviewed machine macros.

## References

- [Engineering document index](../../../Docs/README.md)
- [Needle, bed-mesh, TCP, and live-offset stack](../../../Docs/needle-bed-mesh-tcp-offset-stack.pdf)
- [Custom TCP module](config/scripts/README.md)
- [Official Klipper documentation](https://www.klipper3d.org/)
- [Official Moonraker file API](https://moonraker.readthedocs.io/en/latest/external_api/file_manager/)
- [Official Moonraker printer API](https://moonraker.readthedocs.io/en/latest/external_api/printer/)

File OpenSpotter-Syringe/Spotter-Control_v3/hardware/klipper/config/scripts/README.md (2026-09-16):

# Klipper Custom Scripts

`tcp_calibration.py` is a Klipper `extras` module for continuous optical-cross
TCP calibration.

The routine performs one pure-X acquisition, then centers X with diagonal
sweeps normal to the X beam while following the needle upward to its tip edge.
At `tip_z - 2 mm`, it re-centers X, follows the physical X beam to cross and
center Y, solves both beam coordinates in that common Z plane, and accepts the
result only when stationary sequential queries report both beams `PRESSED`.
The fixture convention is a clear start on the right/X+ side: acquisition moves
X-, the X beam rises toward X-, and the Y beam rises toward X+.

For this workspace it is installed here:

```text
../klipper-master/klippy/extras/tcp_calibration.py
```

From this `scripts` folder, refresh that workspace copy with:

```powershell
Copy-Item -LiteralPath .\tcp_calibration.py -Destination ..\klipper-master\klippy\extras\tcp_calibration.py -Force
```

Remove the workspace copy with:

```powershell
Remove-Item -LiteralPath ..\klipper-master\klippy\extras\tcp_calibration.py
```

For a printer deployment, copy the same file to the active Klipper source tree:

```sh
cp ~/printer_data/config/scripts/tcp_calibration.py ~/klipper/klippy/extras/tcp_calibration.py
sudo systemctl restart klipper
```

Remove the printer deployment with:

```sh
rm ~/klipper/klippy/extras/tcp_calibration.py
sudo systemctl restart klipper
```

Then include `tcp_calibration.cfg` when installed, or remove that include when
the Python module has been removed.

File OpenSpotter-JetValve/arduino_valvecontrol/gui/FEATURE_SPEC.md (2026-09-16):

# Spotter Solenoid Control - Feature Specification

## Purpose
Desktop UI owns all settings and sends pulse commands to an Arduino-controlled solenoid output.
The Arduino only executes pulses and reports errors or pulse-activation messages.

## Architecture
- GUI: PyQt5 app in `app.py`
- Serial transport: `serial_client.py`
- Firmware protocol: `src/main.cpp`

## Serial Protocol
- `S:onMin:onMax:offMin:offMax`: set timing ranges
- `O:<ms>`: set ON time directly
- `P:<ms>`: set OFF time directly
- `E` / `R`: ON minus/plus one step
- `D` / `F`: OFF minus/plus one step
- `K:<count>`: trigger a burst of `count` cycles using the current ON/OFF values

## Firmware Responses
- `ERR ...`: invalid command or invalid parameter
- `ACT pulse=<n> phase=HIGH|LOW`: pulse activation updates

## UI Functional Requirements
- Auto-detect/select the most likely COM port.
- Connect/disconnect serial session.
- Show status text for connection and protocol errors.
- Show and control:
  - ON min/max, slider, current value label
  - OFF min/max, slider, current value label
  - cycle count
- Keyboard shortcuts:
  - `E`/`R` for ON down/up
  - `D`/`F` for OFF down/up
  - `K` for sending pulses
- Keep sliders clamped to current range.
- Prevent invalid range send (`min >= max`).
- Prevent transient typing values from being transmitted (example: typing 900 should not send 9).

## Behavioral Rules
- The GUI is authoritative for settings.
- The Arduino must not overwrite UI state with a separate state model.
- On connect:
  - open port
  - allow command entry
- On disconnect/read failure:
  - close serial
  - stop timers
  - show disconnected state
- On range change:
  - commit text edits first
  - validate ranges
  - sync sliders
  - send range plus current values
- On shot:
  - commit edits
  - validate ranges
  - push current range plus current values
  - send burst command

## Non-Goals
- No running mode.
- No persistent device state synchronization.
- No plotting/history views.

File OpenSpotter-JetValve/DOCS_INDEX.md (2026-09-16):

# Documentation Index

This project keeps a compact, task-focused documentation set.

## Start Here

1. [README.md](README.md)
Purpose: run the app and get high-level context.

2. [GETTING_STARTED.md](GETTING_STARTED.md)
Purpose: practical contributor workflow.

3. [PROJECT_DESCRIPTION.md](PROJECT_DESCRIPTION.md)
Purpose: architecture and project scope.

4. [AGENTS.md](AGENTS.md)
Purpose: mandatory Codex workflow, contribution rules, and change log.

## Human Setup Docs

- [docs/PI_CR6_CONNECTION.md](docs/PI_CR6_CONNECTION.md): end-to-end Pi + CR6 setup flow.
- [docs/START_TO_FINISH_FLOW.md](docs/START_TO_FINISH_FLOW.md): plain-language walk-through of what happens after pressing Start.
- [docs/FLASH_KLIPPER_CR6.md](docs/FLASH_KLIPPER_CR6.md): firmware flash notes.
- [docs/WIRING_DIAGRAM.md](docs/WIRING_DIAGRAM.md): high-level wiring safety notes.
- [docs/ARDUINO_VALVE_BRIDGE.md](docs/ARDUINO_VALVE_BRIDGE.md): Pi USB Arduino valve timing bridge setup.
- [docs/GUI_INTEGRATION.md](docs/GUI_INTEGRATION.md): GUI to Moonraker integration contract.
- [docs/TROUBLESHOOT_CONNECTION.md](docs/TROUBLESHOOT_CONNECTION.md): connection diagnostics.
- [docs/klipper_configs/README.md](docs/klipper_configs/README.md): reusable Klipper snippets and GUI-edited start/end G-code notes.

## AI Maintenance Docs

- [AGENTS.md](AGENTS.md): mandatory Codex workflow, contribution rules, doc-update rules, and compact project context.

## Code Entry Points

- [main.py](main.py)
- [views/main_window.py](views/main_window.py)
- [controllers/main_controller.py](controllers/main_controller.py)
- [services/klipper_service.py](services/klipper_service.py)
- [utils/signals.py](utils/signals.py)

## Maintenance Policy

Whenever behavior, architecture, setup, commands, or configuration changes, update code and documentation in the same change and add an AGENTS change-log note.

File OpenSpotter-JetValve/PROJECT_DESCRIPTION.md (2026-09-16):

# Project Description

## Purpose

Klipper OpenSource Spotter is a PyQt6 desktop application for drop-on-demand spotting workflows.
It provides UI control for valves and macro execution while integrating with Moonraker/Klipper.

## Scope

- GUI-first operation for machine control and monitoring
- Spotting/canvas workflows and progress feedback
- Live toolhead position display on the spotting canvas
- Config-driven machine connection and behavior
- Extensible architecture for future camera and print logic

## Architecture

- Models: core data structures and state
- Views: PyQt6 panels and canvas widgets
- Controllers: orchestration and interaction logic
- Services: external integrations (Moonraker, camera, logging)
- Utils: shared config, helpers, signal bus

## Current Status

Implemented:
- Main window and panel composition
- Signal bus and event-based communication
- Moonraker connectivity (REST + WebSocket client with subscribed toolhead position updates)
- Moonraker-backed Pi file editor for config/scripts, local Pi-target file upload prompts, Klipper restart, and Moonraker-authorized service actions.
- Core model layer and model tests
- Hardware-only spotting workflow with live progress updates
- Klipper valve firing routes through the provided valve macros, with spotting using the unified `SHOOT` wrapper.
- The provided Klipper snippet preloads Arduino timing through the Pi-side bridge and uses Pi host-MCU GPIO edges for per-spot firing in continuous-motion mode.
- The GUI sends configured connect G-code after Moonraker connects; the current default starts the Arduino valve bridge service.
- Spotting sends a single `SHOOT` command per spot with `X`, `Y`, and `SPEED_MM_S`; the Klipper macro places the `G1` move and Pi-MCU Arduino trigger edge together without adding a hard `M400` stop. Zero pre/post waits leave motion continuous, while configured waits intentionally add timing delay around the shot.
- Spotting now checks X/Y homing before dispatch so invalid motion commands do not get sent to Klipper.
- Spotting start preflight uses cached WebSocket toolhead status instead of repeated blocking REST status queries.
- Spotting dispatch uses a configurable send-ahead window. The first dispatch sends up to `dispatch_window_spots`; after `dispatch_refill_threshold_spots` more spots complete, the controller tops the in-flight queue back up to the window. `dispatch_batch_spots` still limits how many lines are grouped into one Moonraker script request.
- Spotting sequence planning is virtual and row-indexed: large grids expose indexed `Spot` objects on demand instead of storing every spot. Position completion projects only the dispatched, incomplete window, not the full planned path.
- Spotting progress follows WebSocket `motion_report.live_position` samples in Pi-MCU trigger mode because trigger edges are queued with motion; USB fallback follows completed Arduino fire command responses.
- The spotting canvas shows the latest toolhead position as a black X from live gantry position updates.
- Roll-to-roll canvas mode avoids full-Y rendering for large row counts by drawing two anchored rows per active grid and a top-right `current/total` row legend per grid.
- Active Stop and app shutdown are soft stops: they stop local dispatch/refill, unblock a paused spotting worker, and clear pending publisher scripts without requesting Moonraker emergency stop. Already accepted Klipper batches are allowed to drain.
- The background status listener uses the WebSocket status cache when connected and avoids repeated REST polling on the hot path.
- Spotting now aborts immediately on Moonraker/Klippy disconnect so the UI does not hang on a dead command queue.
- Valve config editing now uses per-valve tabs and omits pulse-width fields.
- Standalone valve control bar has been removed; fire actions live inside each valve config tab.
- Machine configuration editing is limited to machine, gantry, Klipper, and valve settings; grid definitions are edited from the main window grid panel.
- Grid valve assignment is now embedded in each grid tab as a dropdown.
- Grid sets can now be emptied completely and rebuilt from zero.
- Grid names are editable per tab and tab labels stay tied to the stored grid name.
- Grid tabs include an Active toggle, and inactive grids are skipped by the spotting sequence.
- Grid changes now trigger a full canvas redraw so active grids remain visible after load or add.
- Grid visuals are layered above the background matrix grid so the active layout stays on top.
- Grid valve selectors only expose active valves.

Temporary TODO:
- Calibration manager and calibration workflow are removed for now to avoid broken imports while that feature is reworked.

In progress / partial:
- End-to-end spotting workflow refinement
- Full camera acquisition and processing
- Broader integration and regression test coverage

## Maintenance Boundary

- [AGENTS.md](AGENTS.md) is the source of truth for Codex and contributor workflow.
- Generated files, caches, virtualenv contents, and runtime logs are not source files.
- Future feature work should extend the closest existing model, controller, service, view, signal, and config pattern before introducing new abstractions.
- Hardware-facing changes should be based on code, config, and log evidence, not assumptions.

## Non-Goals (Current Version)

- Production-ready vision stack
- Fully automatic calibration pipeline
- Cloud backend or remote fleet orchestration

## Success Criteria

- App starts reliably and connects when Moonraker is reachable
- Core user actions are reflected in UI and logs
- Config changes are loaded/saved consistently
- Documentation remains aligned with behavior

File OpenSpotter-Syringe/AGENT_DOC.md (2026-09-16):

# AGENT_DOC

Compact machine-oriented context for maintainers and automation.

## Identity

- Project: OpenSpotter-Syringe
- Stack: Python, Tkinter, Pillow, Klipper configuration/G-code, custom Klipper extra
- Target controller in supplied config: Einsy RAMBo 1.1a
- Primary domain: syringe liquid handling and spotting

## Runtime commands

- Install: `cd Spotter-Control_v3 && python -m pip install -r requirements.txt`
- Run: `cd Spotter-Control_v3 && python main.py`
- Compile: `cd Spotter-Control_v3 && python -m compileall -q app`
- Test: `cd Spotter-Control_v3 && python -m unittest discover -s tests -v`

## Active architecture

- Bootstrap and paths: `app/main_v3.py`, `app/paths.py`
- Main UI: `app/gui_v3.py`
- Global parameter window: `app/machine_parameters_window.py`
- Direct-control presentation/coordinator: `app/machine_control_panel.py`, `app/machine_controller.py`
- Moonraker runtime/settings/state/events: `app/machine`, `app/moonraker_connection_window.py`
- Strict direct-run snapshots/artifacts: `app/runtime_job.py`
- Shared dark scientific theme: `app/ui_theme.py`
- Input schemas: `app/input_configs.py`
- Pattern UI: `app/plugins/<plugin>/editor.py`; `app/grid.py` and
  `app/spiral_grid.py` are compatibility exports
- Canvas objects and optional program links: `app/canvas_drawer.py`, `app/visual_objects.py`, `app/visual_object_editor.py`
- Generation orchestration: `app/gcode_generation.py`, `app/grid_gcode.py`, `app/spiral_gcode.py`, `app/gcode_shared.py`
- Shared numeric lifecycle: `app/core/gcode/lifecycle.py`; pattern planning:
  `app/plugins/<plugin>/planner.py`
- Workflow validation/rendering/editor: `app/gcode_workflow.py`, `app/gcode_editor.py`
- Pattern plugins: `app/plugins`
- Canonical workflow: `config/config_gcode_workflow.json`
- Canonical visual objects and bindings: `config/config_visual_objects.json`
- Active hardware include graph: `hardware/klipper/config/printer.cfg`
- Canonical custom Klipper extra: `hardware/klipper/config/scripts/tcp_calibration.py`

## Invariants

- UI colors and fonts come from `ui_theme.py`; do not reintroduce per-window palettes.
- Workflow blocks are event hooks. Python retains lifecycle ordering and numeric syringe state.
- Generated sidecars use schema version 3 generic plugin recipes, retain
  built-in schema-version 2 arrays for migration, and use the suffix
  `_settings.json`; profile loading is JSON-only.
- Loading a profile rebuilds registered plugin workspaces. An embedded workflow is validated and written to the active workflow config.
- Saving with both recipe types creates separate `_grid.gcode` and `_spiral.gcode` jobs and matching profiles.
- `output/gcodes` is ignored runtime output and intentionally contains no examples.
- Canvas rectangles and images use top-left coordinates; circles use centre coordinates. Unlinked geometry is display-only; optional schema-version 2 X/Y/width/height bindings resolve from real program inputs, and guarded reverse writes must honor the global machine-parameter lock.
- Visual-object persistence is painter order from back to front; the editor displays the reverse so higher rows are topmost and layer moves preserve the current appearance until explicitly reordered.
- The canvas origin is the CAPTRON TCP crossing, X0/Y0, with positive X right and positive Y down. The default editable CAPTRON image is 60 × 60 mm and uses `assets/Captron-TCP.png`.
- Build plate, acceptance area, containers, and CAPTRON placeholder all live in the persisted visual-object collection; axes and generated job previews do not.
- Klipper config targets Einsy RAMBo 1.1a. TMC2130 sections live only in `tmc2130.cfg`.
- The include graph has one Mainsail config, one owner for each TMC section, and no firmware source checkout.
- `SET_BLTOUCH_DOCK_STATE` initializes verified state without motion.
- TCP calibration requires homed XYZ, TCP power on, and saved BLTouch state `parked`.
- The Y stepper direction and TCP beam normals are configured for positive Y from the TCP toward the work area; changing that convention requires re-commissioning homing and recalibrating TCP.
- Needle offsets require `tcp_ready=True` and `tcp_coordinate_version=2` by default. Absolute G0/G1 targets add saved TCP offsets; Z also adds the live surface trim. Relative moves remain deltas.
- Raw G0.1/G1.1 bypass the normal correction wrapper and are reserved for reviewed machine macros.
- Direct Start uploads with `print=false`, repeats ready/idle preflight, then calls `printer.print.start`; never replace this with upload auto-start unless queued-job cleanup is proven.
- State-changing commands are not replayed after reconnect. A timeout or disconnect after send is an unknown outcome and normal controls remain interlocked until monitoring reconnects; HTTP Emergency Stop remains available.
- Direct-run recipe names reject CR/LF/control characters. Workflow/profile templates are executable machine code and the final confirmation includes workflow and artifact hashes.
- Direct-run work is bounded before the worker starts, artifacts are capped at 50 MB, identical remote content uses a SHA-256 filename, and only the newest 20 local runtime artifacts per mode are retained.
- Start preflight requires locked globals, ready/idle Klippy, live axis bounds, a loaded saved BLTouch state for `MESH`, and TCP readiness at coordinate version 2 for needle offsets.
- The G-code viewer cursor is virtual-SD read/queued position, never proof of completed physical motion, and is hidden on filename mismatch.
- Direct controls require the immutable advertised `OPENSPOTTER_CONTRACT_V3` plus the reviewed manual/job macro set, including `OPENSPOTTER_JOB_HOME` and `OPENSPOTTER_JOB_REHOME_Z`; missing or stale firmware keeps controls disabled.
- Deploy `hardware.cfg`, `movement_safety.cfg`, `remote_control.cfg`, and the matching `config_gcode_workflow.json` as one motion-control set, then restart Klipper.
- Sensorless X/Y/Z use `homing_retract_dist: 0`. `OPENSPOTTER_HOME` owns the 2-second settle/release Z/Y/physical-clearance/X sequence and requires at least 35 mm plus enabled dead-zone clearances before X home.
- `OPENSPOTTER_JOG` requires homed XYZ, idle/inactive virtual SD, offsets and bed mesh off, physical bounds, and at least 30 mm/min.
- Manual console input is bounded to 16 KiB/100 lines/50 commands and a small query plus `G90`/`G91`/bounded `G0`/`G1` XYZ/F allowlist; raw motion requires explicit mode/feed, live bounds, and at most 60 seconds estimated execution.
- Manual `M112` uses HTTP Emergency Stop. Unsafe/unknown commands are blocked, and partial errors, missing sentinels, timeouts, disconnects, or E-stop latch controls until inspection and reconnect.
- Live Z validates and prechecks motion before coordinate-mode changes, restores state, then commits the offset; desktop changes use `SAVE=0`.
- The sample Moonraker authorization trusts localhost only. Deployment must allow only the exact control host/isolated subnet and firewall port 7125.
- A fixed IPv4 address can avoid `.local`/mDNS connection delay on constrained Pi Zero deployments.

## Folder contract

- Source: `Spotter-Control_v3/app`
- Defaults/state: `Spotter-Control_v3/config`
- Canvas-import assets: `Spotter-Control_v3/assets`
- Static GUI images: `Spotter-Control_v3/assets/images`
- Runtime output: `Spotter-Control_v3/output/gcodes`
- Tests: `Spotter-Control_v3/tests`
- Klipper files: `Spotter-Control_v3/hardware/klipper`
- Mechanical design: `CAD`
- Engineering references: `Docs`

## Known limits

- Hardware-in-the-loop coverage is manual.
- Moonraker/controller tests use fakes; they do not authorize physical motion or prove network/hardware timing.
- The supplied workflow does not run TCP calibration or automatically load/park the detachable BLTouch.
- CAD folders do not provide a formal released-build manifest; verify files against the intended physical revision.
- JetValve, computer vision, and automatic lid handling are not implemented.

## Change log

- 2026-07-16: Added the immutable OpenSpotter contract v3 capability gate, safe sensorless job/manual homing, physical-frame jog/dead-zone checks, and the bounded parsed manual console with HTTP E-stop and partial-outcome interlocks.
- 2026-07-16: Added persistent Moonraker HTTP/WebSocket control, immutable exact virtual-SD artifacts, guarded Start/Pause/Resume/Cancel/E-stop, XYZ jog/home, live Z, read/queued G-code context, connection settings, unknown-outcome interlocks, live bounds/tool readiness, deterministic remote files, retention, and compiled workflow performance caches.
- 2026-07-16: Moved global machine parameters into a persistent maximized editor beside Help and replaced the former reference-imagery space with responsive Machine Control tabs.
- 2026-07-16: Limited application generation to grid and spiral jobs by removing the obsolete standalone calibration UI/event path and its dedicated wait setting; startup needle calibration and hardware TCP calibration remain separate.
- 2026-07-16: Added persistent Move Up/Move Down visual layering with a front-to-back editor list while preserving existing canvas appearance and stored painter order.
- 2026-07-16: Added persistent visual-property bindings to stable numeric program inputs, automatic legacy-container X/Y migration, live canvas resolution with safe fallbacks, and lock-aware reverse editing.
- 2026-07-16: Reflected the machine Y convention to positive-down, including the canvas transform, Y stepper direction, and TCP beam geometry/acquisition defaults.
- 2026-07-16: Added imported image objects with exact millimetre scaling, portable project paths, external-file selection, and cached Tk rendering; migrated CAPTRON to the editable image type.
- 2026-07-16: Moved all former static canvas overlays into the runtime visual-object editor, retained the scalable CAPTRON placeholder, and changed rectangle rendering from stippled mesh to solid fill.
- 2026-07-15: Centralized a graphite/grey scientific UI in `ui_theme.py`; updated all project documentation to the current source and hardware layout; removed stale screenshots, legacy deployment material, generated examples, and the vendored Klipper checkout.
- 2026-07-15: Consolidated hardware configuration around `printer.cfg`, singular `mainsail.cfg`, `syringe.cfg`, and `tmc2130.cfg`; added the non-moving BLTouch state initializer while retaining optical TCP calibration and movement-offset safety.
- 2026-07-15: Consolidated generation around numeric planning plus a runtime-editable workflow, schema-version 2 JSON profiles, atomic output, and focused tests; profile loading is now JSON-only.
- 2026-07-15: Rebased the preview on TCP X0/Y0 and added separately persisted, display-only rectangles and circles.
- 2026-07-09: Reworked TCP calibration for X acquisition, upward X-beam tip tracking, same-plane X/Y centring, stationary beam verification, and persisted TCP offsets.

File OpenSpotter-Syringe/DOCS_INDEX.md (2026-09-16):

# Documentation Index

## Start

- [README.md](README.md): syringe-platform overview and current capabilities.
- [GETTING_STARTED.md](GETTING_STARTED.md): install, validate, generate, and hardware preflight.
- [PROJECT_DESCRIPTION.md](PROJECT_DESCRIPTION.md): scope, architecture, and maturity.

## Application

- [Spotter-Control_v3/README.md](Spotter-Control_v3/README.md): user-facing application behavior.
- [Spotter-Control_v3/DEPLOYMENT.md](Spotter-Control_v3/DEPLOYMENT.md): package, standalone, and runtime-data deployment.
- [Spotter-Control_v3/VERSIONING.md](Spotter-Control_v3/VERSIONING.md): release and compatibility version policy.
- [Spotter-Control_v3/CHANGELOG.md](Spotter-Control_v3/CHANGELOG.md): user-visible change history.
- [Spotter-Control_v3/ARCHITECTURE.md](Spotter-Control_v3/ARCHITECTURE.md): core/plugin dependency rules, lifecycle, runtime boundaries, and migration status.
- [Spotter-Control_v3/PLUGIN_DEVELOPMENT.md](Spotter-Control_v3/PLUGIN_DEVELOPMENT.md): external entry points, plugin APIs, hooks, compatibility, and tests.
- [Spotter-Control_v3/Spotter_Control_Dev.md](Spotter-Control_v3/Spotter_Control_Dev.md): source map and developer contracts.
- [Spotter-Control_v3/config/config_gcode_workflow.json](Spotter-Control_v3/config/config_gcode_workflow.json): active machine-command workflow.
- [Spotter-Control_v3/config/config_visual_objects.json](Spotter-Control_v3/config/config_visual_objects.json): display-only canvas layout.

## Hardware and design

- [Spotter-Control_v3/hardware/klipper/README.md](Spotter-Control_v3/hardware/klipper/README.md): Klipper deployment, commissioning, calibration, and safety.
- [Spotter-Control_v3/hardware/klipper/config/scripts/README.md](Spotter-Control_v3/hardware/klipper/config/scripts/README.md): custom TCP module installation.
- [CAD/README.md](CAD/README.md): design generations and manufacturing exports.
- [Docs/README.md](Docs/README.md): BOM, schematics, datasheets, calibration diagrams, and photos.

## Maintenance

- [AGENTS.md](AGENTS.md): contribution and documentation rules.
- [AGENT_DOC.md](AGENT_DOC.md): compact machine-oriented architecture and invariants.

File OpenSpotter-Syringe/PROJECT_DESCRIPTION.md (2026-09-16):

# Project Description

## Purpose

OpenSpotter-Syringe is a research platform for repeatable syringe-based deposition. Its desktop application turns experiment recipes into Klipper-compatible G-code while keeping machine-command templates editable and the numeric process lifecycle in tested Python code.

## System boundaries

The repository contains:

- a local Tkinter control and planning application;
- a persistent Moonraker WebSocket/HTTP runtime for monitored virtual-SD execution and guarded manual control;
- grid, cleaning, washing, rinse, and spiral planners;
- an event-driven, runtime-editable G-code workflow;
- JSON defaults, UI state, visual-layout objects, and generation profiles;
- Klipper configuration for an Einsy RAMBo 1.1a syringe platform;
- a custom optical-cross TCP calibration extra;
- CAD generations, manufacturing exports, BOM, schematics, and component references.

It does not contain a JetValve implementation, computer vision, or automatic lid control.

## Architecture

The desktop stack is split into stable services and replaceable patterns:

1. `app/core/` owns schemas, atomic storage, domain/geometry values,
   workflow/plugin contracts, renderer-neutral canvas models, and the shared
   G-code lifecycle.
2. `app/plugins/grid/` and `app/plugins/spiral/` own their fields, editors,
   numeric/event planning, saved and direct-run generation, canvas previews,
   and workflow metadata/representative values.
3. `app/plugin_runtime.py` discovers built-in and installed
   `openspotter.patterns` entry points. `app/gui_v3.py` builds workspaces and
   routes profiles, generation, previews, and direct-run capture through those
   contracts.
4. `app/gcode_workflow.py` validates and renders event templates from writable
   runtime configuration. Generated files are atomic and use schema-version 3
   plugin profiles, with legacy built-in arrays retained for migration.
5. `app/runtime_job.py`, `machine_controller.py`, `machine_control_panel.py`,
   and `app/machine/` capture bounded immutable plugin recipes, generate exact
   artifacts, validate live machine readiness/bounds, and coordinate Moonraker
   without blocking Tk.

`app/canvas_drawer.py` combines plugin-owned preview primitives around TCP
X0/Y0 without importing a concrete pattern. Unlinked values in
`config/config_visual_objects.json` are display annotations only. Optional
geometry links resolve from real program inputs; visual geometry never
constrains motion or enters planning directly, while a guarded reverse edit
intentionally changes the linked program input.

The former top-level grid, spiral, G-code, planner, and helper modules remain
export-only compatibility facades. New code imports the owning core or plugin
module. See [Spotter-Control_v3/ARCHITECTURE.md](Spotter-Control_v3/ARCHITECTURE.md)
and [Spotter-Control_v3/PLUGIN_DEVELOPMENT.md](Spotter-Control_v3/PLUGIN_DEVELOPMENT.md).

The firmware side is modular Klipper configuration under `Spotter-Control_v3/hardware/klipper/config`. The custom `tcp_calibration.py` module must be installed into the printer's active Klipper source tree.

Direct execution uses content-addressed virtual-SD files. It uploads without Moonraker auto-start queueing, repeats ready/idle preflight, and starts through one persistent JSON-RPC connection. Subscribed state drives Pause/Resume/Cancel, guarded XYZ motion, live needle Z, prompts, positions, and the virtual-SD read/queued cursor. HTTP Emergency Stop remains independent of the WebSocket command queue.

## Current maturity

Implemented and covered by repository tests:

- workflow validation/rendering and safe expressions;
- numeric planning edge cases;
- grid/spiral generation integration;
- compiled workflow output equivalence and cache reuse;
- Moonraker reconnect/no-replay behavior, command timing, unknown outcomes, upload/start preflight, emergency HTTP, and Tk event bridging;
- controller snapshot-to-upload/start ordering, live bounds/tool readiness, filename matching, and interlocks;
- visual-object validation and persistence;
- static hardware-configuration invariants.

Still requiring physical validation:

- wiring, homing sensitivity, travel limits, docking geometry, and syringe calibration;
- optical TCP repeatability and offset sign conventions on each build;
- bed mesh, live Z trim, dead-zone definitions, and complete hardware-in-the-loop jobs;
- material compatibility and experiment-specific safety.

This repository is a research implementation, not a production-grade laboratory automation system.

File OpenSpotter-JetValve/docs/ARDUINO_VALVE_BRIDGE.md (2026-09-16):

# Arduino Valve Bridge

Use this when the Arduino is connected to the Raspberry Pi over USB and the GUI sends motion through Moonraker/Klipper.

Current working paths:

- MCU trigger mode: preload timing once, then Klipper pulses the Pi host-MCU GPIO at each spot.
- USB bridge mode: Klipper calls the bridge directly and the console shows the JSON response. Use it as an explicit manual fallback, not as the continuous spotting path.
- The Arduino uses interrupt inputs D2 and D3 for GPIO trigger edges only after timing preload arms each trigger. `VALVE=0` fires D7, and `VALVE=1` fires D6.

The older USB-only immediate trigger path remains available with `TRIGGER_MODE=usb`.

## Find The Arduino Port On The Pi

Prefer the stable by-id path:

```bash
ls -l /dev/serial/by-id/
```

Fallback checks:

```bash
dmesg | grep -E "tty(ACM|USB)"
python3 -m serial.tools.list_ports -v
```

Use a path like `/dev/serial/by-id/usb-Arduino__www.arduino.cc__0043...` instead of `/dev/ttyACM0` when possible, because `ttyACM0` can change after reboot.

## Pi Setup

Install the serial dependency from apt:

```bash
sudo apt update
sudo apt install python3-serial
```

Do not use `python3 -m pip install pyserial` against the Pi system Python on Raspberry Pi OS Bookworm; it is externally managed. If the apt package is unavailable, create a venv and run the bridge with that venv's Python.

```bash
python3 -m venv ~/spotter-valve-venv
~/spotter-valve-venv/bin/python -m pip install pyserial
```

If the project is on the Windows PC, create the Pi target folder over SSH and copy the bridge scripts with `scp` from PowerShell:

```powershell
ssh pi@R2R-SPOTTER-PLOTTER.local "mkdir -p /home/pi/printer_data/config/scripts"
scp .\scripts\arduino_valve_bridge.py pi@R2R-SPOTTER-PLOTTER.local:/home/pi/printer_data/config/scripts/
scp .\scripts\arduino_valve_fire.py pi@R2R-SPOTTER-PLOTTER.local:/home/pi/printer_data/config/scripts/
```

Then on the Pi:

```bash
chmod +x /home/pi/printer_data/config/scripts/arduino_valve_*.py
```

If the project is already cloned on the Pi, copy locally instead:

```bash
mkdir -p /home/pi/printer_data/config/scripts
cp scripts/arduino_valve_bridge.py /home/pi/printer_data/config/scripts/
cp scripts/arduino_valve_fire.py /home/pi/printer_data/config/scripts/
chmod +x /home/pi/printer_data/config/scripts/arduino_valve_*.py
```

## Terminal Tests

### 1. Check the bridge service on the Pi

Start the persistent bridge manually if you are not using the systemd service yet:

```bash
python3 /home/pi/printer_data/config/scripts/arduino_valve_bridge.py \
  --serial-port /dev/serial/by-id/usb-1a86_USB_Serial-if00-port0 \
  --baud 9600 \
  --valves 0,1
```

Then verify the bridge endpoint:

```bash
curl http://127.0.0.1:8765/status
curl "http://127.0.0.1:8765/configure?valve=0&on_ms=16&off_ms=5&cycles=1"
curl "http://127.0.0.1:8765/fire?valve=0&on_ms=2&off_ms=2&cycles=1"
curl "http://127.0.0.1:8765/configure?valve=1&on_ms=16&off_ms=5&cycles=1"
curl "http://127.0.0.1:8765/fire?valve=1&on_ms=2&off_ms=2&cycles=1"
```

### 2. Fire the valve directly over USB from a Pi shell

This is the fastest end-to-end check when you want the Arduino to actuate immediately:

```bash
curl "http://127.0.0.1:8765/fire?valve=0&on_ms=16&off_ms=5&cycles=1"
curl "http://127.0.0.1:8765/fire?valve=1&on_ms=16&off_ms=5&cycles=1"
```

### 3. Test MCU-trigger mode from the Klipper console

This path tests the Pi host-MCU GPIO edge path. `TEST_ARDUINO_VALVE` preloads timing and then sends the rising trigger pulse in MCU mode:

```text
SET_ARDUINO_VALVE_TIMING VALVE=0 ON_MS=16 OFF_MS=5 CYCLES=1
TEST_ARDUINO_VALVE VALVE=0 ON_MS=16 OFF_MS=5 CYCLES=1
SET_ARDUINO_VALVE_TIMING VALVE=1 ON_MS=16 OFF_MS=5 CYCLES=1
TEST_ARDUINO_VALVE VALVE=1 ON_MS=16 OFF_MS=5 CYCLES=1
```

If you want to test the underlying move-and-fire macro directly, use `TRIGGER_MODE=mcu` explicitly:

```text
SHOOT VALVE=0 PRE_FIRE_WAIT=0 POST_FIRE_WAIT=0 TRIGGER_MODE=mcu
SHOOT VALVE=1 PRE_FIRE_WAIT=0 POST_FIRE_WAIT=0 TRIGGER_MODE=mcu
```

### 4. Test the USB bridge macro from Klipper

Use this when you want the visible bridge JSON in the console:

```text
SHOOT VALVE=0 ON_MS=16 OFF_MS=5 CYCLES=1 TRIGGER_MODE=usb
SHOOT VALVE=1 ON_MS=16 OFF_MS=5 CYCLES=1 TRIGGER_MODE=usb
```

Do not use the USB bridge fallback as the normal continuous spotting path. It runs a shell command through Klipper, while MCU mode keeps per-spot firing inside the Klipper move queue with `SET_PIN`.

For a realtime check on the Pi, query the motion report instead of the queued toolhead target:

```bash
curl http://127.0.0.1:7125/printer/objects/query?motion_report
```

Look for `result.status.motion_report.live_position` in the JSON output. If that value only changes at the end of the move, the issue is below the GUI subscription layer because Mainsail and the GUI read from Moonraker/Klipper status streams.
```

For normal use, run the bridge as a boot service instead of starting it from a terminal or from G-code:

```bash
sudo nano /etc/systemd/system/spotter-arduino-valve-bridge.service
```

Use this service file, replacing `YOUR_ARDUINO_ID` with the stable `/dev/serial/by-id/...` path:

```ini
[Unit]
Description=Spotter Arduino valve bridge
After=network.target

[Service]
Type=simple
User=pi
ExecStart=/usr/bin/python3 /home/pi/printer_data/config/scripts/arduino_valve_bridge.py --serial-port /dev/serial/by-id/YOUR_ARDUINO_ID --baud 9600 --valves 0,1
Restart=always
RestartSec=2

[Install]
WantedBy=multi-user.target
```

If you installed `pyserial` in `~/spotter-valve-venv` instead of with `apt`, use the venv Python in `ExecStart`:

```ini
ExecStart=/home/pi/spotter-valve-venv/bin/python /home/pi/printer_data/config/scripts/arduino_valve_bridge.py --serial-port /dev/serial/by-id/YOUR_ARDUINO_ID --baud 9600 --valves 0,1
```

Enable and start it:

```bash
sudo systemctl daemon-reload
sudo systemctl enable --now spotter-arduino-valve-bridge.service
sudo systemctl status spotter-arduino-valve-bridge.service
```

View logs:

```bash
journalctl -u spotter-arduino-valve-bridge.service -f
```

If `systemctl status` shows `status=1/FAILURE`, read the real error:

```bash
journalctl -u spotter-arduino-valve-bridge.service -n 80 --no-pager
systemctl cat spotter-arduino-valve-bridge.service
```

Common causes:

- `/usr/bin/python3` cannot import `serial`; use `sudo apt install python3-serial` or change `ExecStart` to `/home/pi/spotter-valve-venv/bin/python`.
- The bridge script is not at `/home/pi/printer_data/config/scripts/arduino_valve_bridge.py`.
- The Arduino by-id path is wrong or missing.

Do not start the persistent bridge from `SHOOT` G-code. Stock Klipper cannot start external commands, and with `gcode_shell_command` the G-code waits for the command to exit or time out. Starting the long-running bridge per shot would also create duplicate bridge processes or port conflicts. G-code should only trigger the already-running bridge.

## Start The Bridge From Mainsail

You can start the systemd service from a Klipper macro so you do not need to open a terminal each time. This starts the service manager unit, not the long-running bridge process directly.

First confirm the systemctl path on the Pi:

```bash
command -v systemctl
```

The provided macro uses `/usr/bin/systemctl`. If your Pi returns a different path, update `docs/klipper_configs/valve_macros.cfg` before copying it to the Pi.

Allow the Klipper user to start and restart only this service without a password:

```bash
sudo visudo -f /etc/sudoers.d/spotter-arduino-valve-bridge
```

Add this line if Klipper runs as user `pi`:

```text
pi ALL=(root) NOPASSWD: /usr/bin/systemctl start spotter-arduino-valve-bridge.service, /usr/bin/systemctl restart spotter-arduino-valve-bridge.service
```

Then copy the updated [docs/klipper_configs/valve_macros.cfg](klipper_configs/valve_macros.cfg) to the Pi config folder, restart Klipper, and run either macro from Mainsail:

```text
START_ARDUINO_VALVE_BRIDGE
RESTART_ARDUINO_VALVE_BRIDGE
```

The GUI also sends `START_ARDUINO_VALVE_BRIDGE` automatically after it connects to Moonraker. This is configured in [config/machine_config.json](../config/machine_config.json) as:

```json
"connect_gcode": "START_ARDUINO_VALVE_BRIDGE"
```

If Klipper runs under a different user, replace `pi` in the sudoers line with that user. Check with:

```bash
ps -o user= -C klippy
```

Do not enter the Raspberry Pi password into Mainsail, the macro, or the GUI. The macro uses `sudo -n`, which refuses to prompt for a password. If Mainsail reports `sudo: a password is required`, the sudoers rule is missing, has the wrong user, or does not exactly match the `/usr/bin/systemctl ... spotter-arduino-valve-bridge.service` command.

After saving the sudoers rule, test it on the Pi as the Klipper user:

```bash
sudo -n /usr/bin/systemctl start spotter-arduino-valve-bridge.service
systemctl status spotter-arduino-valve-bridge.service
curl http://127.0.0.1:8765/status
```

## Pi Host MCU Trigger Setup

[docs/klipper_configs/printer.cfg](klipper_configs/printer.cfg) includes the Pi host MCU:

```ini
[mcu rpi]
serial: /tmp/klipper_host_mcu
```

The macro snippet defines these trigger outputs:

```ini
[output_pin arduino_valve_trigger_0]
pin: rpi:gpio17

[output_pin arduino_valve_trigger_1]
pin: rpi:gpio27
```

Verify the pins against your actual wiring before enabling the macro. The required wiring is:

- Raspberry Pi GPIO17 (`rpi:gpio17`) -> Arduino D2 trigger for `VALVE=0`
- Raspberry Pi GPIO27 (`rpi:gpio27`) -> Arduino D3 trigger for `VALVE=1`
- Arduino D7 -> valve 0 MOSFET control signal
- Arduino D6 -> valve 1 MOSFET control signal
- Pi GND connected to Arduino GND

The Arduino inputs use normal digital inputs and hardware interrupts on `CHANGE`, but the firmware only fires if the pin level is still changed when the main loop consumes the interrupt. Klipper toggles the matching Pi GPIO once for each spot. This keeps one queued edge per spot while ignoring short coupled spikes that have already returned to the previous level. If false triggers remain, add about a 10k pulldown from each Arduino trigger input to GND close to the Arduino. Do not connect any Arduino 5 V output back into a Raspberry Pi GPIO.

The `SET_ARDUINO_VALVE_TIMING` preload also arms the selected valve trigger, which keeps the Arduino from firing on boot-time pin noise or startup edges before the run is configured.

## Klipper Setup

The macro snippet in [docs/klipper_configs/valve_macros.cfg](klipper_configs/valve_macros.cfg) uses both the local bridge and the Pi host MCU trigger.

Requirements:

- Arduino connected to the Pi over USB.
- Pi host MCU configured and connected to Klipper.
- Pi trigger GPIO17 wired to Arduino D2 and GPIO27 wired to Arduino D3 with common ground.
- `arduino_valve_bridge.py` running on the Pi.
- `arduino_valve_fire.py` copied to the path used by the macro.
- Klipper `gcode_shell_command` extension installed, because stock Klipper does not provide `RUN_SHELL_COMMAND`.

If Mainsail reports this error:

```text
Section 'gcode_shell_command arduino_valve_fire' is not a valid config section
```

then the Klipper shell-command extension is missing. Install or reinstall it with KIAUH:

```bash
cd ~
git clone https://github.com/dw-0/kiauh.git
./kiauh/kiauh.sh
```

In KIAUH, install **G-Code Shell Command** from the advanced/extensions menu, then restart Klipper. If KIAUH is already installed, run `~/kiauh/kiauh.sh` instead of cloning again.

Confirm the extension file exists:

```bash
ls ~/klipper/klippy/extras/gcode_shell_command.py
```

After installation, restart Klipper from Mainsail or run:

```bash
sudo systemctl restart klipper
```

After setup, the GUI sends `SET_ARDUINO_VALVE_TIMING ...` before the run for each active valve when `klipper.valve_trigger_mode` is `mcu`, then sends `SHOOT VALVE=... X=... Y=... SPEED_MM_S=... PRE_FIRE_WAIT=... POST_FIRE_WAIT=... TRIGGER_MODE=mcu` for each spot. The per-spot MCU `SHOOT` command intentionally omits `ON_MS`, `OFF_MS`, and `CYCLES`; the preload is the only timing source. The Klipper macro places the `G1` move and one queued Pi-MCU GPIO edge in one macro call. Zero pre/post waits leave motion continuous; non-zero waits intentionally add timing delay around the shot. The Arduino owns valve pulse timing after it receives the GPIO edge.

## Arduino Firmware

The current Arduino sketch can fire valve 0 on D7 and valve 1 on D6. The bridge selects the valve with `V:<id>`, then uses the legacy timing commands `O:<ticks>`, `P:<ticks>`, and either `K:<cycles>` for immediate USB fire or `C:<cycles>` for MCU-trigger preload. The `C` preload arms the selected trigger path so startup edges are ignored until the run has been configured. The sketch uses 0.1 ms ticks and clamps both ON and OFF timing to a minimum of 2 ms.

For MCU trigger mode, flash the checked-in Arduino sketch because it adds the D2/D3 interrupt trigger inputs. The Pi bridge sends `V/O/P/C` before spotting starts; each stable Pi-MCU GPIO edge then starts the selected valve's preloaded burst. The USB-only fallback still sends `V/O/P/K` for every shot.

If a manual `SHOOT` command seems to do nothing in MCU mode, make sure the Pi host MCU trigger is enabled and use `TRIGGER_MODE=mcu` explicitly or `TEST_ARDUINO_VALVE`.

Current verified pin map:

- `VALVE=0`: Arduino D7 output, Arduino D2 interrupt trigger from Pi GPIO17
- `VALVE=1`: Arduino D6 output, Arduino D3 interrupt trigger from Pi GPIO27

Do not enable additional valve IDs until the Arduino output pin map and driver wiring are verified.

## Timing Boundary

MCU trigger mode removes the per-shot USB serial shell call from the timing path. It still depends on the Raspberry Pi host MCU timing path, not the CR6 motion MCU. If host-MCU jitter is still too high for the required dot placement, move the trigger output to a verified CR6/Klipper MCU pin.

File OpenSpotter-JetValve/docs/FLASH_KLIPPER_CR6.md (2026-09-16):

# Flash Klipper to CR6

## Steps

1. Build firmware from your chosen CR6-compatible Klipper source.
2. Copy firmware binary to SD card as firmware.bin.
3. Insert SD into CR6 and power cycle.
4. Confirm file renamed (firmware flashed).
5. Connect CR6 to Pi via USB.
6. Configure [mcu] serial path in printer.cfg.
7. Restart Klipper and verify MCU ready in logs.

## Commands

```bash
ls /dev/serial/by-id/*
sudo systemctl restart klipper
sudo systemctl status klipper
tail -f ~/printer_data/logs/klippy.log
```

## Common Failures

- bad USB cable (power-only)
- wrong serial path in [mcu]
- invalid config include/order
- failed flash due to SD formatting issues

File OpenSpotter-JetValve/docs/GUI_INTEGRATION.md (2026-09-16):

# GUI Integration with Moonraker

## Data Flow

1. User action in UI
2. Signal emitted via AppSignals
3. Controller receives signal
4. Service sends request to Moonraker
5. Toolhead status updates arrive over Moonraker WebSocket subscriptions
6. Result is logged and reflected in UI

## Main Integration Points

- Signal definitions: [utils/signals.py](../utils/signals.py)
- Controller handling: [controllers/main_controller.py](../controllers/main_controller.py)
- Moonraker client: [services/klipper_service.py](../services/klipper_service.py)

## API Endpoints

- GET /api/server/info
- POST /api/gcode/script
- GET /api/printer/info
- GET /api/printer/objects/query?toolhead
- POST /printer/print/pause and POST /printer/print/cancel for Mainsail-style print controls
- POST /printer/emergency_stop only for true emergency-stop behavior
- GET /server/files/roots, GET /server/files/list, GET /server/files/{root}/{path}, and POST /server/files/upload for the Pi file editor
- GET /machine/system_info and POST /machine/services/{start|stop|restart} for Moonraker-authorized service status/actions
- POST /printer/restart for the Pi file editor's save-and-restart path
- WebSocket `printer.objects.subscribe` for `toolhead.position` and `toolhead.homed_axes`

**Auth & Routing**

- If Moonraker is configured to require API keys or authorization, the GUI's Moonraker client supports passing HTTP headers (e.g. `Authorization`/Bearer tokens). Configure `services.MoonrakerClient(headers={...})` accordingly.
- If Moonraker uses a `route_prefix` (see Moonraker docs), include it when constructing the client so endpoints resolve correctly.

## Minimum Manual Test

1. Start app.
2. Confirm status panel changes to connected.
3. Send a simple macro.
4. Verify success in Moonraker/Klipper logs.

## Notes

- Keep macro format and parameter naming aligned with [docs/klipper_configs/valve_macros.cfg](klipper_configs/valve_macros.cfg).
- Grid spots in MCU trigger mode preload timing once with `SET_ARDUINO_VALVE_TIMING`, then send one `SHOOT` command with `X`, `Y`, `SPEED_MM_S`, `HOLD`, `PRE_FIRE_WAIT`, `POST_FIRE_WAIT`, and `TRIGGER_MODE=mcu`. USB fallback `SHOOT` commands include `ON_MS`, `OFF_MS`, and `CYCLES`.
- Buildplate canvas mode renders every active grid spot. Roll-to-roll canvas mode renders two anchored rows per active grid and a stacked `current/total` row legend so large row counts do not allocate thousands of visual rows.
- After Moonraker connects, the main controller sends `klipper.connect_gcode`; the current default is `START_ARDUINO_VALVE_BRIDGE`.
- Spotting dispatch must not block each move on a REST position query. Live position display can use cached toolhead status, but MCU-mode spotting completion is driven only by WebSocket `motion_report.live_position` samples. At run start, the GUI clears prior completed spots, records a timestamped run boundary, and projects fresh live-position samples only onto the dispatched, incomplete spot window so sparse updates can still complete crossed spots in sequence without caching the full path. Klipper macro responses, Moonraker JSON-RPC responses, and `toolhead.position` target updates are not physical completion signals. `dispatch_window_spots` is the maximum in-flight send-ahead window, and `dispatch_refill_threshold_spots` is the completed-spot count that triggers a top-up. For example, window 10 and threshold 5 sends spots 1-10, then 11-15 when 5 are complete, then 16-20 when 10 are complete. `dispatch_batch_spots` still limits how many lines are grouped into one Moonraker script request.
- Pressing Stop or closing the app during an active spotting run does not request Moonraker `/printer/emergency_stop`. It stops local dispatch/refill and clears pending local publisher scripts; already accepted Klipper batches are allowed to drain. The emergency endpoint remains reserved for actual emergency-stop UI because Moonraker documents it as a shutdown path.
- Stale `SPOTTER_SHOOT_DONE` macro messages from older Pi-side configs are ignored by the GUI to avoid log and console flooding. The current checked-in `valve_macros.cfg` should still be copied to the Pi because Klipper itself can be slowed by excessive g-code response output.
- The `Pi_Files` top-bar action is disabled until Moonraker connects, then opens a Moonraker-backed file editor. The Pi is treated as the source of truth. File editor Moonraker calls run in background worker threads and return UI updates through Qt signals; do not run blocking file API calls on the GUI thread. From the editor reload/upload controls, the GUI compares local Pi-target files from `docs/klipper_configs/*` and `scripts/arduino_valve_*.py` against the Pi `config` root and asks before uploading Windows copies. The per-file `Copy To Local` action downloads the current Pi file and overwrites the mapped local copy only after confirmation.
- Pi file editor open, reload, root listing, file listing, download, upload, sync prompt, Klipper restart, service actions, and caught exceptions are logged to `logs/dod_system.log`.
- The service tab only shows and controls services that Moonraker reports in `machine.system_info.available_services`; add project-specific services such as the Arduino bridge to Moonraker's allowed services if they should be controllable there.
- Spotting start preflight uses cached WebSocket `toolhead` status and waits only briefly for homing status after start G-code; repeated blocking REST status queries should not be added back to the start path.
- Valve timing is preloaded through the Pi-side Arduino bridge in the provided macro snippet; the per-spot trigger is a Pi host-MCU GPIO edge when `klipper.valve_trigger_mode` is `mcu`.
- `SHOOT` has no async flag. Zero `PRE_FIRE_WAIT` and `POST_FIRE_WAIT` leaves motion continuous after the embedded `G1`; non-zero waits intentionally add timing delay around the Arduino trigger. Live position display should follow the `motion_report.live_position` WebSocket updates, not the queued `toolhead.position` target. Do not add an unconditional `M400` unless stationary stop-at-each-spot behavior is intended.
- The current verified Arduino pin map supports `VALVE=0` on Arduino D7 triggered through D2 from Pi GPIO17, and `VALVE=1` on Arduino D6 triggered through D3 from Pi GPIO27. Additional valve IDs require verified Arduino wiring and firmware changes.
- Burst timing with `CYCLES>1` is handled by the Arduino after the Pi-MCU trigger edge instead of streaming valve output edges through Klipper.
- Update this file if signal names or endpoint usage changes.

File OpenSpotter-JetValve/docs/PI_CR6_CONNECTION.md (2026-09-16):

# Raspberry Pi + CR6 Connection

This is the shortest path to bring up Pi, CR6, Klipper, the Arduino valve bridge, and Spotter.

## Steps

1. Flash Pi with MainsailOS.
2. Flash Klipper to CR6 (see [FLASH_KLIPPER_CR6.md](FLASH_KLIPPER_CR6.md)).
3. Copy config snippets from [klipper_configs](klipper_configs) to the Pi config folder.
4. Connect the Arduino valve controller to the Pi over USB, wire Pi GPIO17 to Arduino D2 for valve 0, wire Pi GPIO27 to Arduino D3 for valve 1, and set up [ARDUINO_VALVE_BRIDGE.md](ARDUINO_VALVE_BRIDGE.md).
5. Restart services:

```bash
sudo systemctl restart klipper
sudo systemctl restart moonraker
```

6. Set [config/machine_config.json](../config/machine_config.json) host to the Pi IP.
7. Run Spotter on Windows:

```bash
python main.py
```

## Validate

- Moonraker API returns 200 from /api/server/info
- Arduino bridge returns 200 from http://127.0.0.1:8765/status on the Pi
- `curl "http://127.0.0.1:8765/configure?valve=0&on_ms=16&off_ms=5&cycles=1"` returns `ok`
- `curl "http://127.0.0.1:8765/configure?valve=1&on_ms=16&off_ms=5&cycles=1"` returns `ok`
- `TEST_ARDUINO_VALVE VALVE=0` pulses Pi GPIO17 and fires Arduino D7
- `TEST_ARDUINO_VALVE VALVE=1` pulses Pi GPIO27 and fires Arduino D6
- GUI status shows connected
- Macro execution from GUI works

## Related docs

- [FLASH_KLIPPER_CR6.md](FLASH_KLIPPER_CR6.md)
- [ARDUINO_VALVE_BRIDGE.md](ARDUINO_VALVE_BRIDGE.md)
- [GUI_INTEGRATION.md](GUI_INTEGRATION.md)
- [TROUBLESHOOT_CONNECTION.md](TROUBLESHOOT_CONNECTION.md)

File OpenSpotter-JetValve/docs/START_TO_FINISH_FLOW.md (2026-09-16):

# Start to Finish Flow

This page explains what happens in simple steps after you press **Start** in the GUI and before the spotting job ends.

## What Start Does

1. You click **Start** in [views/controls_panel.py](../views/controls_panel.py).
2. The controls panel sends a `spotting_start_requested` signal with sequence settings; live grid definitions supply per-grid speed.
3. [controllers/spotting_controller.py](../controllers/spotting_controller.py) receives the signal and begins the spotting run.
4. The controller builds a row-indexed virtual spot sequence from the active grids, so large grids can be indexed without storing every spot object.
5. If there are no active grids, the job stops immediately and a warning is logged.
6. The controller reads the Moonraker host and port from config.
7. When the main window connects to Moonraker, it sends the configured `klipper.connect_gcode`; the current default starts the Arduino valve bridge service through `START_ARDUINO_VALVE_BRIDGE`.
8. The app reuses the already-connected Moonraker client from the main window and reads the cached WebSocket toolhead state.
9. The app sends the configured start G-code line by line.
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

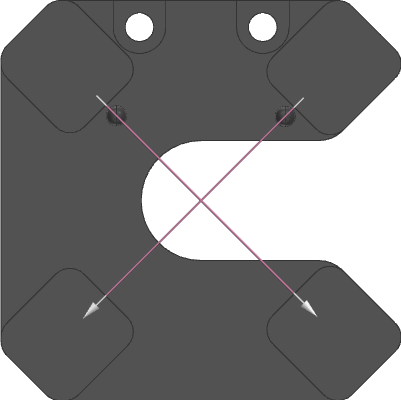
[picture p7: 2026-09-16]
OpenSpotter-Syringe/Spotter-Control_v3/assets/Captron-TCP.png

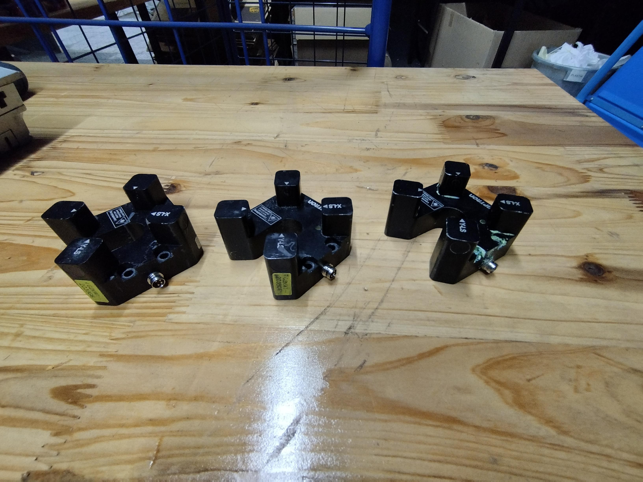
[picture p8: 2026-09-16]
OpenSpotter-Syringe/Docs/TCP_4.jpg

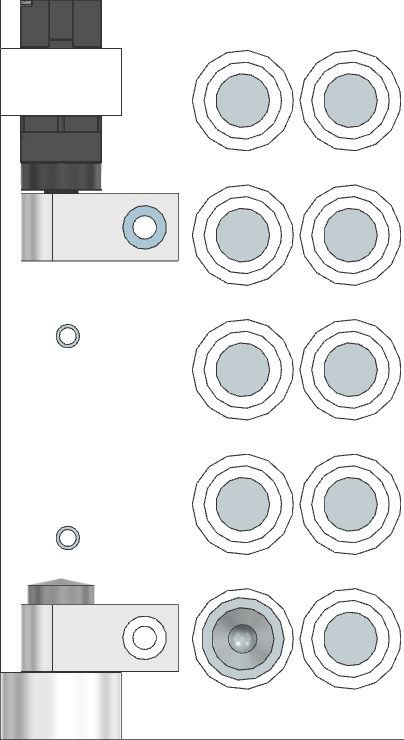
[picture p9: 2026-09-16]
OpenSpotter-Syringe/Spotter-Control_v3/assets/LoadingBay.png

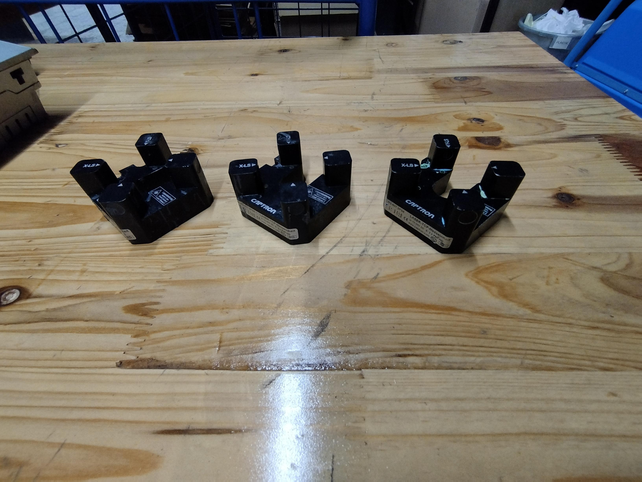
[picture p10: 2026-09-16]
OpenSpotter-Syringe/Docs/TCP_2.jpg

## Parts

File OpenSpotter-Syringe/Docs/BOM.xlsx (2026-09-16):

BOM - Syringe Spotter V2
 |  |  | EUR |  | Total
 | PART NAME & Link | Supplier | Price | Status
 | 10 uL Syringe (https://www.sigmaaldrich.com/DK/en/product/sial/20682) | Sigma-Aldrich | 54.45 | WAITING | 734.59 | €
 | BL-Touch (https://3deksperten.dk/products/3d-touch-spider-ex-creality-cr10-cr10s-ender-3-ender-3-pro) | 3D-ExpertenDK | 16.05 | SOURCED
 | SD-CARD (https://3deksperten.dk/products/micro-sd-kort-16gb) | 3D-ExpertenDK | 9.53 | SOURCED
 | RPI ZERO_W_V2 (https://dk.farnell.com/raspberry-pi/rpi-zero-w-v2/raspberry-pi-kit-64bit-arm-cortex/dp/3838499?src=raspberrypi) | Farnell | 12.94 | SOURCED | 5487.3873 | DKK
 | PRUSA MK3s | SDU | 0 | SOURCED
 | VacuumChuckBaseBlock (https://www.alwa.de/en/ALWA-POR-ALUMINIUM-1-200-x-300-x-20-mm/1118020) | ALWA | 128.02 | SOURCED
 | CONNECTOR-Pins (https://dk.rs-online.com/web/p/printstiftlister/2518418) | RS-Online | 41.9 | SOURCED
 | MICRO-USB-M--USB-A-F (https://dk.rs-online.com/web/p/usb-kabler/1862819) | RS-Online | 5.58 | SOURCED
 | USB-B-M -- USB-A-M (https://dk.rs-online.com/web/p/usb-kabler/1862787) | RS-Online | 5.16 | SOURCED
 | Linear Actuator for Syringe (https://www.omc-stepperonline.com/de/nema-8-schrittmotor-kugelumlaufspindel-linearakkuator-0-5a-hub-60mm-0-01nm-1-416oz-in-steigung-1mm-0-03937-mit-sensor-lmd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) | Stepper-Online | 201.93 | SOURCED |  |  | STATUS
 | LASER Driver (https://ardustore.dk/produkt/pc817-optokobler-2-kanal-3-6-24v-isolation-module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) | Ardustore | 3.25 | ORDER-PENDING |  |  | SOURCED
 | LASER CONNECTOR (https://www.digikey.dk/da/products/detail/altech-corporation/CBF08-R44N0-02BPVC/15851562) | DIGIKEY | 5.2 | ORDER-PENDING |  |  | ORDERED
 | M2.5x 12 | RS-Online | 31 | ORDER-PENDING |  |  | ORDER-PENDING
 | M2.5 Nut | RS-Online | 5.8 | ORDER-PENDING |  |  | CANCELED
 | PETG - Black (https://3deksperten.dk/products/solid-black-3de-premium-petg-1-75mm) | 3D-ExpertenDK | 19.26 | ORDERED |  |  | WAITING
 | TCP Laser (https://industrymall.de/en/plc/30411-captron-oglw2-40t-2ps6-tcp-measuring-instrument-40mm.html) | industrymall | 203.57 | ORDERED
 | PETG - ORANGE (https://3deksperten.dk/products/prusament-petg-prusa-orange-1-75mm-1kg) | 3D-ExpertenDK | 0 | CANCELED
 |  |  |  |  |  |  | IDEAS
 |  |  |  |  |  |  | https://www.mt24.com/en/electronics/sensors/more-sensors/other-sensors/captron-laser-tcp-sensor.html
 |  |  |  |  |  |  | TCP calibration equipment

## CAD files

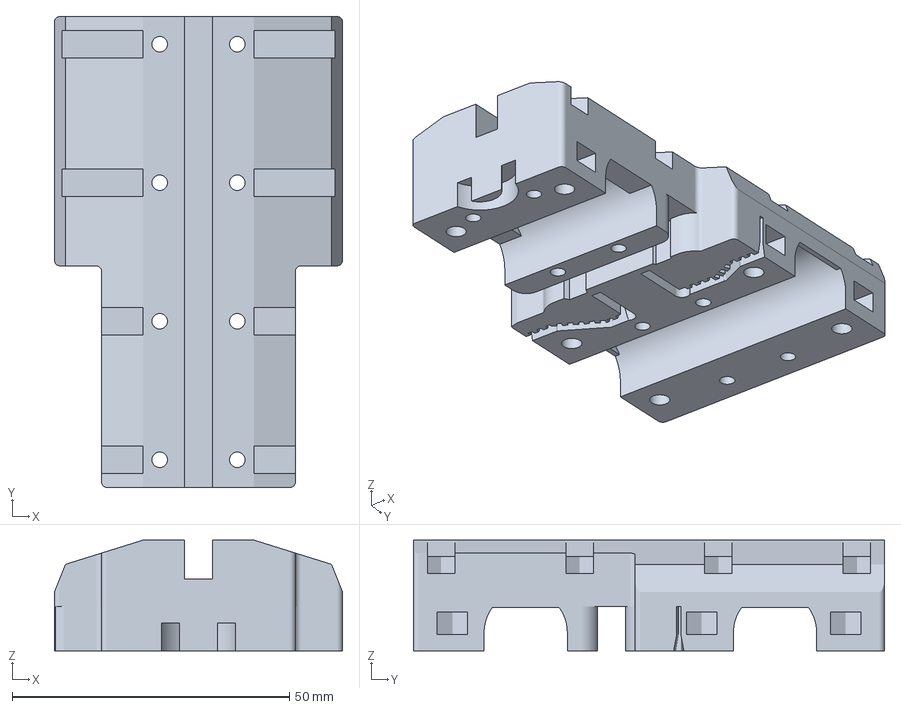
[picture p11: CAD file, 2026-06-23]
OpenSpotter-Syringe/CAD/Syringe_Spotter_V2/3D-Printing/Print_It_1/0ASM_Syringe_Spotter_SDU_V2.3mf
52.0 x 85.0 x 20.0 mm

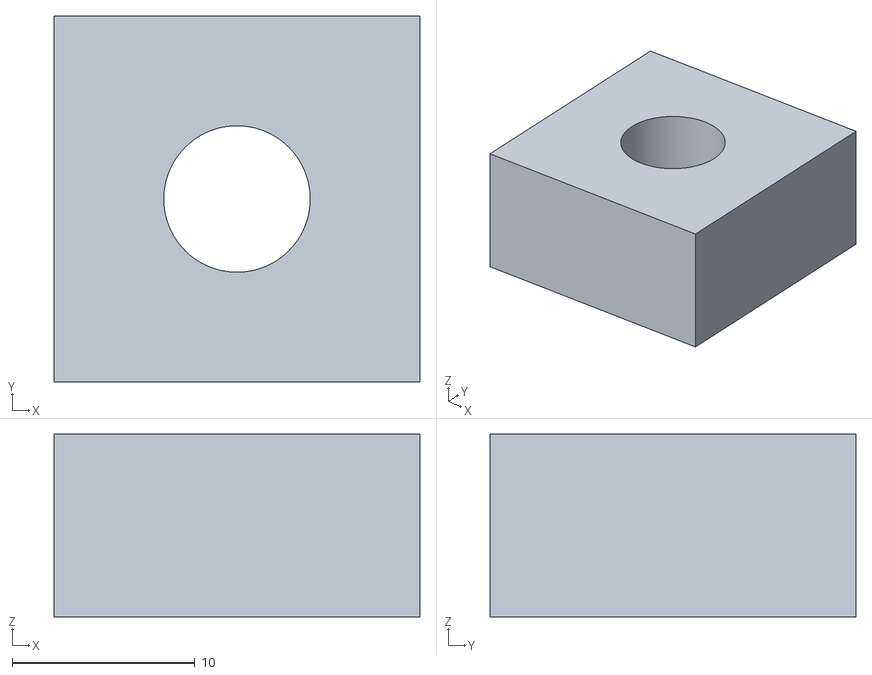
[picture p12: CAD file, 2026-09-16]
OpenSpotter-Syringe/CAD/Syringe_Spotter_V2/3D-Printing/PorBlock_SDU_V2_1.stl
20.0 x 20.0 x 10.0

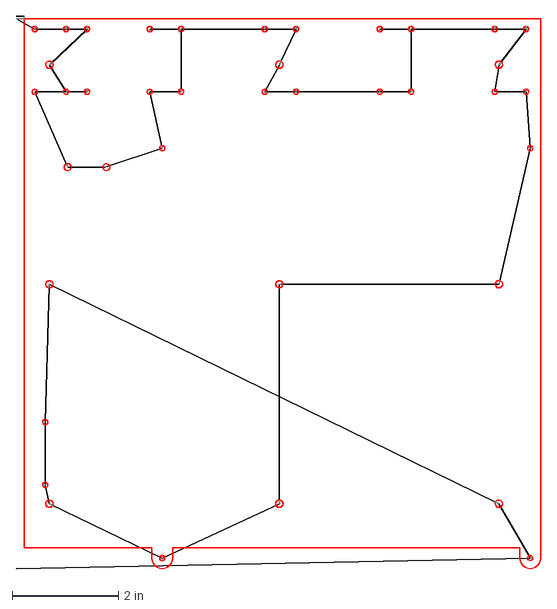
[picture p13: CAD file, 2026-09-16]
OpenSpotter-Syringe/CAD/Syringe_Spotter_V2/Waterjetting/Baseplate_Syringe_Spotter_5mm_Alu.dxf
9.87 x 10.4 in

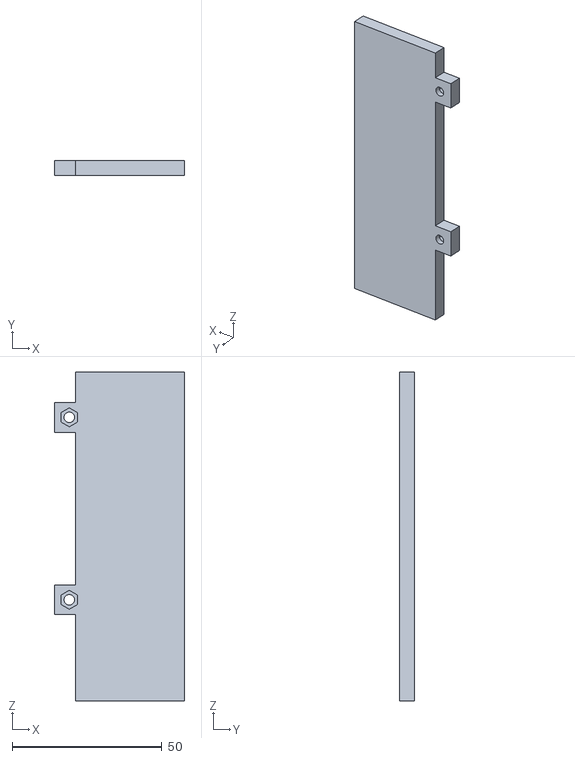
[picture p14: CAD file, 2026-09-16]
OpenSpotter-Syringe/CAD/Syringe_Spotter_V2/3D-Printing/Loading_container_plate_SDU_V2.stl
43.6 x 5.00 x 110.0

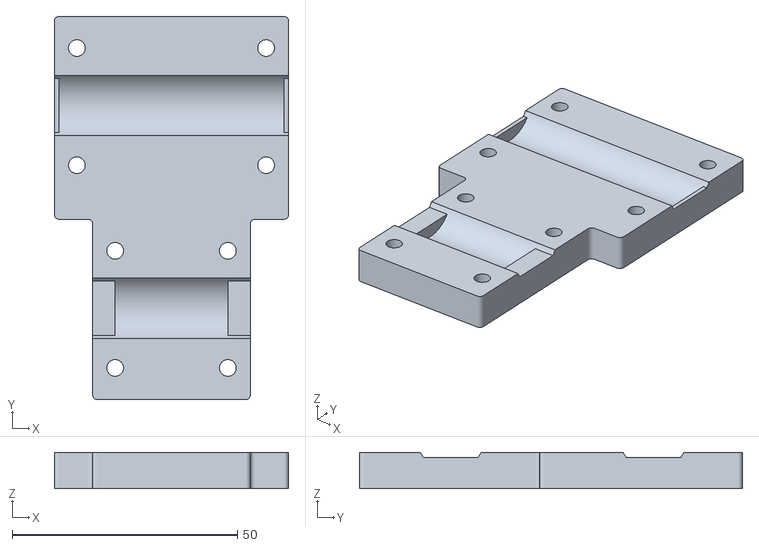
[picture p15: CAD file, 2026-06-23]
OpenSpotter-Syringe/CAD/Syringe_Spotter_V2/3D-Printing/Print_It_1/custom-x-carriage-backplate_SDU_V2.stl
52.0 x 85.0 x 8.00

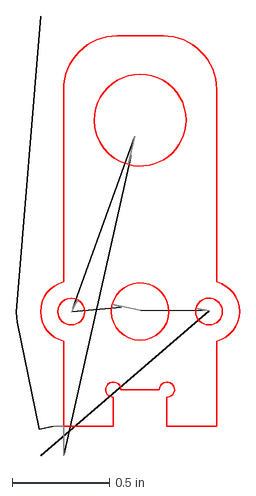
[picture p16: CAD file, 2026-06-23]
OpenSpotter-Syringe/CAD/Syringe_Spotter_V2/Waterjetting/syringe-clamp_SDU_V2_6mm_Alu.dxf
1.15 x 2.26 in

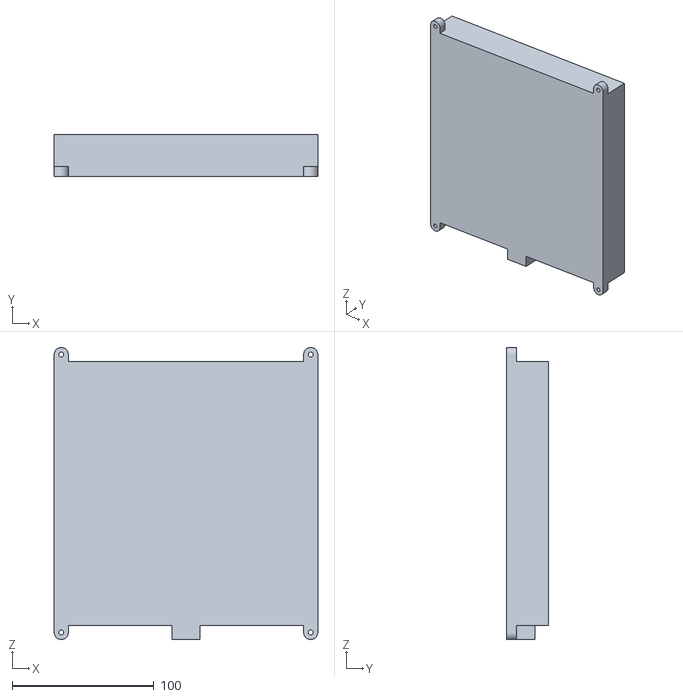
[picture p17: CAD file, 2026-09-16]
OpenSpotter-Syringe/CAD/Syringe_Spotter_V2/3D-Printing/PorBlock_Holder_SDU_V2.stl
186.0 x 29.5 x 206.0

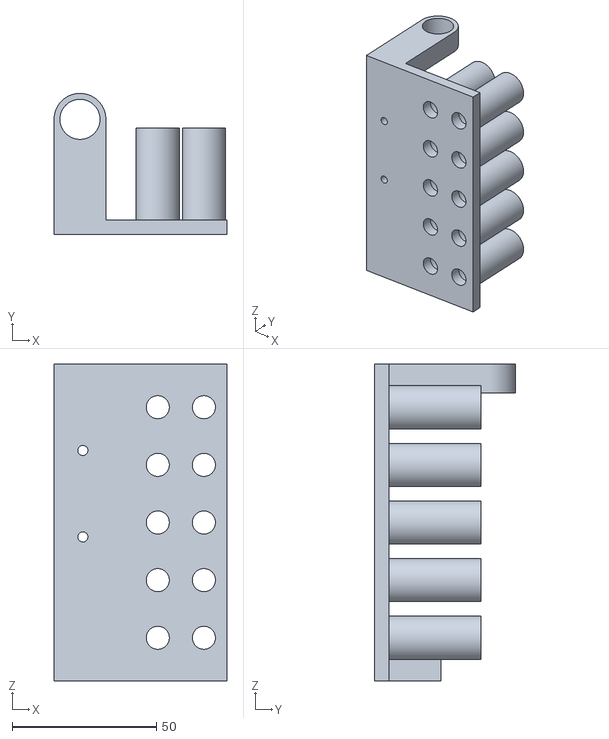
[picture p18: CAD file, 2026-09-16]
OpenSpotter-Syringe/CAD/Syringe_Spotter_V2/3D-Printing/Loading_container_base_SDU_V2.stl
60.0 x 49.0 x 110.0

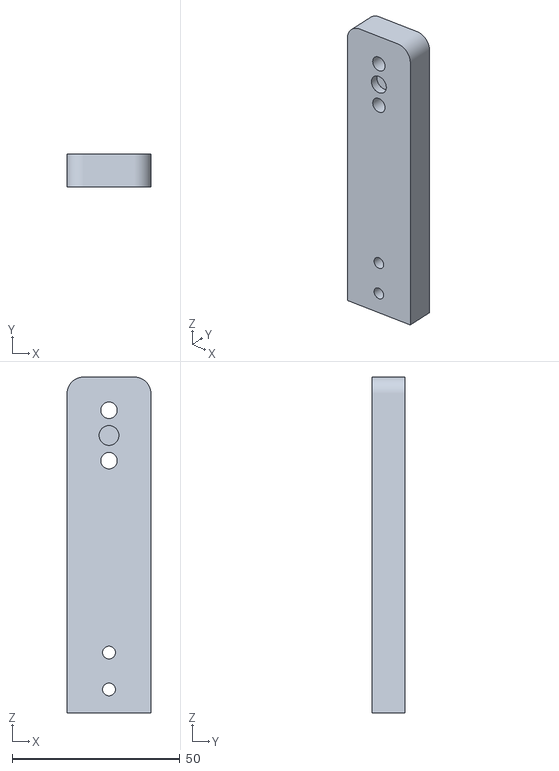
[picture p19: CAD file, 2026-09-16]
OpenSpotter-Syringe/CAD/Syringe_Spotter_V2/3D-Printing/BLtouch_ToolStation2_SDU_V2.stl
25.0 x 9.80 x 100.0

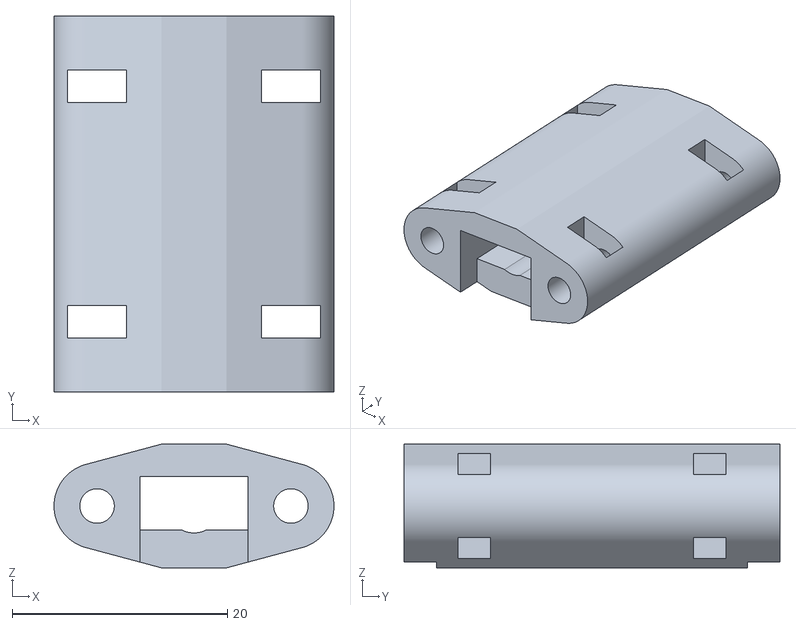
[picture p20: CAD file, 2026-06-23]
OpenSpotter-Syringe/CAD/Syringe_Spotter_V2/3D-Printing/Print_It_1/PolycarbonateHousing_SDU_V2.stl
26.0 x 34.9 x 11.5

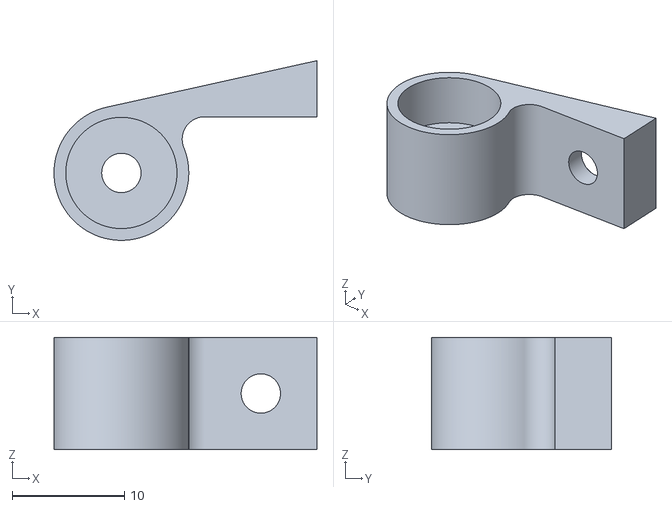
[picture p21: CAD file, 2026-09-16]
OpenSpotter-Syringe/CAD/Syringe_Spotter_V2/3D-Printing/Loading_container_Servo_SDU_V2.stl
23.4 x 16.0 x 10.0

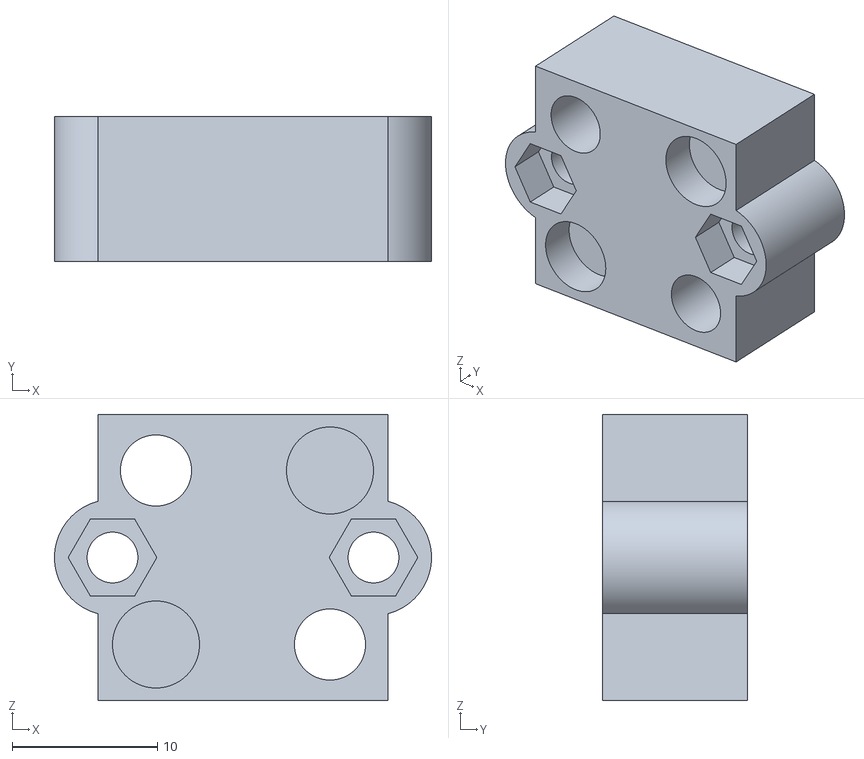
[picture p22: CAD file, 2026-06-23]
OpenSpotter-Syringe/CAD/Syringe_Spotter_V2/3D-Printing/Print_It_1/ToolChangerTop_SDU_V2.stl
26.0 x 10.0 x 19.7

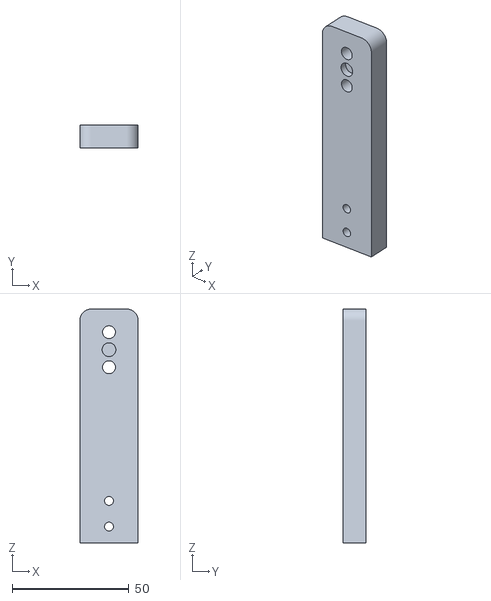
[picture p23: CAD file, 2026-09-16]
OpenSpotter-Syringe/CAD/Syringe_Spotter_V2/3D-Printing/BLtouch_ToolStation1_SDU_V2.stl
25.0 x 10.0 x 100.0

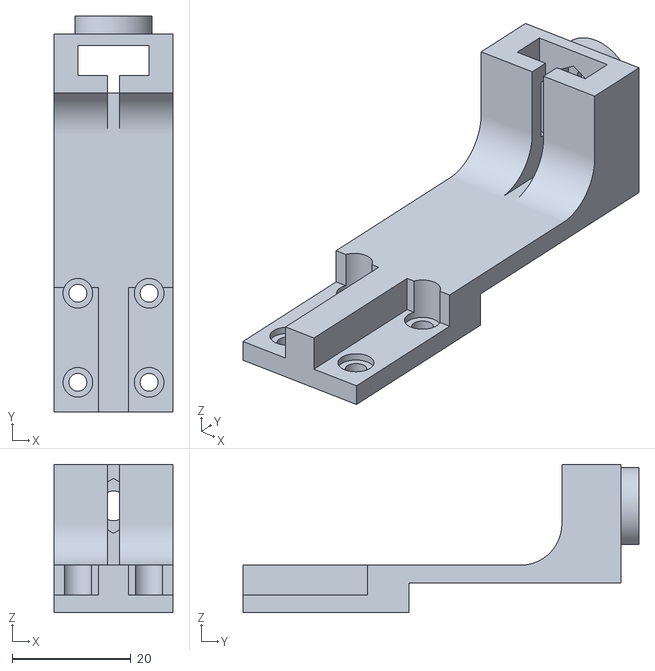
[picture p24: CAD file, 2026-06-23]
OpenSpotter-Syringe/CAD/Syringe_Spotter_V2/3D-Printing/Print_It_1/Syringe_Plunger_Handle_SDU_V2.stl
20.0 x 66.7 x 25.0

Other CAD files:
OpenSpotter-Syringe/CAD/Syringe_Spotter_V2/3D-Printing/Print_It_1/custom-x-carriage_SDU_V2_1.stl
OpenSpotter-Syringe/CAD/Syringe_Spotter_V2/3D-Printing/Loading_container_servomount_SDU_V2.stl
OpenSpotter-Syringe/CAD/Syringe_Spotter_V2/3D-Printing/Print_It_1/ToolChangerBL_SDU_V2.stl
OpenSpotter-Syringe/CAD/Syringe_Spotter_V2/3D-Printing/TCP_OPTOCOUPLER_Housing_1.stl
OpenSpotter-Syringe/CAD/Syringe_Spotter_V1/0ASM_Syringe_Spotter_SDU_V1.prt
OpenSpotter-Syringe/CAD/Syringe_Spotter_V1/21114_Slider_v1_SDU_V1.prt
OpenSpotter-Syringe/CAD/Syringe_Spotter_V1/21117_Rail_L100_v1_SDU_V1.prt
OpenSpotter-Syringe/CAD/Syringe_Spotter_V1/2229_Z Box_v2_SDU_V1.prt
OpenSpotter-Syringe/CAD/Syringe_Spotter_V1/40-42 motor_thread135_SDU_V1.prt
OpenSpotter-Syringe/CAD/Syringe_Spotter_V1/6x6x3t spacer_SDU_V1.prt
OpenSpotter-Syringe/CAD/Syringe_Spotter_V1/BLTouch v34_SDU_V1.prt
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

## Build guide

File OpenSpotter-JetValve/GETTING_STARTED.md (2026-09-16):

# Getting Started

This guide is for contributors who want to make changes quickly without reading long specs.

## 1. Setup

```bash
pip install -r requirements.txt
python main.py
```

On Windows with the local virtualenv:

```powershell
.\.venv\Scripts\python.exe main.py
```

## 2. Validate Baseline

Run tests before editing:

```bash
pytest tests/ -v
```

If `pytest` is not on PATH:

```powershell
.\.venv\Scripts\python.exe -m pytest tests/ -v
```

## 3. Codex Workflow

1. Read [AGENTS.md](AGENTS.md) and check `git status --short`.
2. For runtime bugs, read the latest entries in `logs/dod_system.log` before drawing conclusions.
3. Inspect the relevant source-of-truth files before editing.
4. Keep changes small and scoped to the requested behavior or setup issue.
5. Prefer existing controller, service, view, signal, and config patterns.
6. Do not invent hardware facts; if Moonraker/Klipper behavior is unclear, verify it in logs or ask.
7. Run focused tests after edits and report any command that could not run.
8. Update human docs and the [AGENTS.md](AGENTS.md) change log when behavior, architecture, setup, commands, or configuration change.

## 4. Key Files

- [main.py](main.py): app entrypoint
- [views/main_window.py](views/main_window.py): top-level UI wiring
- [controllers/main_controller.py](controllers/main_controller.py): app orchestration and Moonraker connection
- [services/klipper_service.py](services/klipper_service.py): Moonraker HTTP/WebSocket client
- [utils/signals.py](utils/signals.py): signal bus contract

## 5. Typical Change Workflow

1. Pick one feature area.
2. Update model/service/controller/view as needed.
3. Keep signal names and payloads consistent.
4. Run tests.
5. Update docs in the same change.

## 6. Hardware Integration Checklist

1. Confirm host and port in config/machine_config.json.
2. Verify Moonraker is reachable.
3. Test macro path from GUI.
4. For valve timing, set up and test [docs/ARDUINO_VALVE_BRIDGE.md](docs/ARDUINO_VALVE_BRIDGE.md).
5. Validate CR6 and Pi-side macros with the checked-in snippets under [docs/klipper_configs](docs/klipper_configs) before changing wiring-facing behavior.

## 7. Documentation Rule

Every behavior change must include updates to at least one of:
- [README.md](README.md)
- [PROJECT_DESCRIPTION.md](PROJECT_DESCRIPTION.md)
- relevant files in [docs](docs)
- [AGENTS.md](AGENTS.md)

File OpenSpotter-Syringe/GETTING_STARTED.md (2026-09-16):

# Getting Started

This guide covers the desktop application and the minimum safe path to inspect the included Klipper configuration. Run commands from `OpenSpotter-Syringe/Spotter-Control_v3`.

## Install and run

Create a virtual environment and install the application in editable mode:

```powershell
python -m venv .venv
.\.venv\Scripts\Activate.ps1
python -m pip install --upgrade pip
python -m pip install -e .
openspotter-control
```

On macOS or Linux, activation is:

```sh
python3 -m venv .venv
source .venv/bin/activate
python -m pip install --upgrade pip
python -m pip install -e .
openspotter-control
```

The app is a local Tkinter program with optional direct Moonraker control. It still opens and generates saved G-code when no printer is available.
`python main.py` and `python -m app` remain supported source launchers. Linux
Python installations may also require `python3-tk`.

## Validate the checkout

```powershell
python -m pip install -e ".[test]"
python -m compileall -q app
python -m unittest discover -s tests -v
```

Source checkouts retain `config`, `logs`, and `output` beside the application.
Installed and standalone builds use per-user writable storage. See
[Spotter-Control_v3/DEPLOYMENT.md](Spotter-Control_v3/DEPLOYMENT.md) for paths,
portable mode, first-run seeding, and migration.

For a visual smoke test, confirm that:

- the window uses the graphite/grey theme;
- global defaults load locked from `config/config_global.json`;
- saved registered-plugin counts restore from `config/config_states.json`;
- the canvas shows the editable 60 × 60 mm CAPTRON image centred at TCP X0/Y0;
- scroll zoom, drag pan, and **FIT VIEW** work;
- **VISUAL OBJECTS** edits persisted rectangles, circles, and imported images; unlinked geometry remains display-only;
- the Visual Objects list is front-to-back, so a higher row appears above a lower row and Move Up/Move Down changes that stack;
- each legacy container circle follows its matching `global.containerN_x/y` values, and reverse editing is blocked until global machine parameters are unlocked;
- **IMPORT IMAGE…** starts in the asset folder, accepts other filesystem paths, and scales the selected image to its entered millimetre width/height;
- **EDIT G-CODE WORKFLOW** validates, previews, and saves workflow changes.
- **MACHINE PARAMETERS** opens the persistent maximized global editor immediately left of **HELP**;
- the right-side Machine Control panel exposes connection state, Start/Pause/Resume/Stop, Emergency Stop, XYZ jog, live Z, and the exact virtual-SD read/queued cursor;
- **CONFIG** opens masked local Moonraker settings and **RETRY** restarts monitoring.

## Generate and reload a job

1. Select Grid or Spiral mode and add at least one recipe.
2. Review global settings, recipe coordinates, volumes, containers, maintenance options, and the workflow.
3. Select **GENERATE G-CODE** and choose a base path.
4. Inspect every generated command before sending it to a machine.

If both grid and spiral recipes exist, choosing `experiment.gcode` produces:

```text
experiment_grid.gcode
experiment_grid_settings.json
experiment_spiral.gcode
experiment_spiral_settings.json
```

Each schema-version 3 settings profile records registered plugin recipes, global
values, derived runtime values, and the effective workflow. Compatibility arrays
for the built-in grid and spiral plugins remain present. **LOAD PROFILE** accepts
JSON only. Loading replaces the current pattern tabs; if the profile contains
`workflow`, the validated embedded workflow is also saved over
`config/config_gcode_workflow.json`.

An embedded workflow is executable machine-command data. The application asks separately before replacing the active workflow, and direct Start shows both the workflow hash and exact artifact hash before upload.

The save dialog starts in `output/gcodes`, which is an ignored runtime directory. Copy outputs to an experiment record or another durable location when they must be retained.

## Connect and run through Moonraker

1. Deploy the current `hardware.cfg`, `movement_safety.cfg`, and `remote_control.cfg` together, retain the matching application `config/config_gcode_workflow.json`, and restart Klipper.
2. Select **CONFIG** in Machine Control and enter the Moonraker host/IP, port, protocol, optional route prefix, and API key. The created `Spotter-Control_v3/config/config_moonraker.json` is local and ignored by Git.
3. In `moonraker.conf`, trust only the exact control PC or isolated machine subnet and firewall TCP port 7125; do not expose motion endpoints to an entire shared private network.
4. Confirm the panel reports connected and Klippy ready.
5. Confirm Klipper advertises `OPENSPOTTER_CONTRACT_V3`, `OPENSPOTTER_JOB_HOME`, and `OPENSPOTTER_JOB_REHOME_Z`. If the contract is missing or stale, Start/Home/jog controls remain disabled.
6. Physically load and verify the detachable BLTouch before a workflow that uses `MESH`.
7. Confirm saved TCP calibration is ready at coordinate version 2.
8. Keep Global Machine Parameters locked, select Grid or Spiral mode, and choose **START CURRENT RECIPE**.
9. Review the captured mode/count, workflow hash, full artifact SHA-256, byte/line count, remote path, and motion warning. Start only if they describe the intended experiment.

Direct Start captures an immutable snapshot, generates it off the Tk thread, checks resource limits and live machine bounds, uploads without auto-start/queueing, repeats the ready/idle check, and then sends one persistent-WebSocket Start request. Identical content uses the same hash-based remote filename. The newest 20 local runtime artifacts per mode are retained.

The G-code tab maps Moonraker’s virtual-SD file cursor to the exact local artifact. This is a read/queued position and may be ahead of physical execution. If a response is lost after a command was sent, the outcome is treated as unknown and normal controls interlock until monitoring reconnects; Emergency Stop remains available.

If `.local` connection setup is slow on a Pi Zero, enter its fixed IPv4 address in **CONFIG**. XYZ jog requires homed XYZ, no active virtual-SD job, needle offsets and bed mesh off, and at least 30 mm/min. Safe Home requires sensorless `homing_retract_dist: 0` and performs reviewed 2-second settle/release cycles plus a physical Z clearance of at least 35 mm and all enabled dead-zone clearances.

The **MANUAL / CONSOLE** editor is for small tests, not arbitrary Klipper administration. It accepts diagnostic queries and bounded `G90`/`G91` plus `G0`/`G1` XYZ/F motion with explicit mode/feed, live bounds, the same homing/offset/mesh/virtual-SD guards, and a 60-second estimated cap. Unknown or safety-bypassing commands are blocked. `M112` uses Moonraker's HTTP Emergency Stop; partial execution errors, timeouts, disconnects, or E-stop keep controls latched until the printer is inspected and monitoring reconnects.

Preflight is not a complete interpreter for arbitrary custom macros. After any workflow/profile/firmware or fixture change, inspect the exact artifact and perform an elevated, fluid-free dry run.

## Before hardware motion

Read the [Klipper hardware guide](Spotter-Control_v3/hardware/klipper/README.md) in full. In particular:

1. Confirm the machine is actually wired as the Einsy RAMBo 1.1a configuration describes.
2. Install the custom `tcp_calibration.py` extra before enabling `tcp_calibration.cfg`.
3. Verify all pins, axis directions, limits, sensorless homing, syringe travel, and emergency-stop behavior with tools clear of the work area.
4. Physically inspect the detachable BLTouch, then initialize its saved state with `SET_BLTOUCH_DOCK_STATE STATE=parked` or `STATE=loaded`. This command records state and does not move the probe.
5. Commission the TCP optics and obtain `tcp_ready=True` before enabling needle-tip offsets.
6. Run a small, elevated, fluid-free job and compare the preview, generated G-code, and physical motion.

The default workflow homes and meshes, but it does not run TCP calibration or automatically load/park the detachable BLTouch. Saved-state preflight reduces mistakes but does not verify physical attachment. Tool-state preparation and controlled hardware commissioning remain explicit operator steps.

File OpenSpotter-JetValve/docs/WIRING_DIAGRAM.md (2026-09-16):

# Wiring Diagram (High Level)

Main path:

```text
Windows Spotter GUI
    -> Moonraker on Raspberry Pi (network)
    -> Klipper on CR6 board plus Raspberry Pi host MCU
    -> Pi host-MCU GPIO triggers into Arduino D2/D3
    -> Arduino valve controller on Raspberry Pi (USB serial for timing preload)
    -> MOSFET drivers
    -> Solenoid valves
```

Current verified control wiring:

```text
Raspberry Pi GPIO17 (Klipper pin rpi:gpio17) -> Arduino D2 trigger input for valve 0
Raspberry Pi GPIO27 (Klipper pin rpi:gpio27) -> Arduino D3 trigger input for valve 1
Raspberry Pi GND -------------------------------- Arduino GND
Arduino D7 -------------------------------------- valve 0 MOSFET driver input
Arduino D6 -------------------------------------- valve 1 MOSFET driver input
```

## Electrical rules

- Do not drive valve coils directly from CR6 MCU pins.
- Use logic-level MOSFET drivers for each valve output.
- Add flyback protection for inductive loads.
- Use a suitable external valve power supply.
- Keep grounds common between Arduino logic, valve driver, and valve supply.
- Keep grounds common between Raspberry Pi and Arduino for the trigger signal.
- Do not connect Arduino 5 V outputs into Raspberry Pi GPIO pins.
- The hardened trigger path accepts stable Arduino D2/D3 trigger edges and ignores short spikes that have returned to the previous level by the time firmware consumes the interrupt. If false triggers remain, add about a 10k pulldown from each trigger input to GND close to the Arduino and route each trigger wire with a nearby ground wire.
- Keep CR6/Klipper on motion control; use the Pi host-MCU trigger only for the verified Arduino trigger input path.

## Safety checklist

- Verify wiring orientation before power-up.
- Confirm Arduino output pin mapping before enabling a valve ID.
- Confirm the Pi GPIOs selected in `valve_macros.cfg` match the wires to Arduino D2 and D3.
- Use gate pull-down resistors to avoid floating gates.
- Run small pulse tests first and monitor logs.

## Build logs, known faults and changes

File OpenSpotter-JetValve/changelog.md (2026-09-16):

## Change Log

- 2026-06-11: Fixed MCU progress completion to ignore target `toolhead.position` samples and use only `motion_report.live_position`.
- 2026-06-11: Optimized spotting backend for large R2R jobs by replacing full spot/path caches with virtual row-indexed sequence access, capped in-flight dispatch top-ups, dispatched-window position projection, and bounded R2R progress keys.
- 2026-06-11: Optimized AGENTS/docs for compact agent use, removed stale CanvasController and generated artifacts, and added R2R two-row canvas rendering with row legends.
- 2026-06-11: Fixed soft Stop after Pause by clearing the worker paused state and marking local spotting dispatch not running while the worker exits.
- 2026-05-26: Made spotting send-ahead and refill-threshold values editable in the Klipper machine config and changed dispatch refill to send the next burst only after the configured completed-spot threshold.
- 2026-05-26: Added a persistent black X live toolhead marker to the spotting canvas using gantry position updates.
- 2026-05-26: Added a Pi file editor Copy To Local action that downloads the selected Pi file into its mapped local project copy after confirmation.
- 2026-05-26: Made the Pi file editor root selector content-aware so root labels and dropdown text are not clipped.
- 2026-05-26: Removed connect-time Pi file sync and moved Pi file editor Moonraker file/service operations to background workers with Qt-signal UI updates.
- 2026-05-26: Disabled the Pi file editor top-bar action until Moonraker reports connected, while keeping the direct open guard.
- 2026-05-26: Added detailed system-log breadcrumbs and exception handling for Pi file editor open, reload, sync, file, service, and restart actions.
- 2026-05-26: Added a Moonraker-backed Pi file editor with config/script save-to-Pi, local Pi-target upload prompts, Klipper restart, and Moonraker-authorized service actions.
- 2026-05-22: Added Codex workflow guidance, tightened stable project docs, removed stale duplicate Klipper example config and unused pulse-width signal, and ignored generated caches, virtualenv files, and runtime logs.
- 2026-05-22: Removed the blocking per-move REST position query from spotting dispatch, added Moonraker WebSocket toolhead status subscription, increased the default spotting lookahead window, and changed async valve macros to delayed off timers instead of G4 dwell.
- 2026-05-23: Added per-grid speed propagation into planned spots, async move feedrates, and the SHOOT SPEED_MM_S macro parameter for synced Klipper moves.
- 2026-05-23: Changed valve burst macros from PWM duty-cycle output to explicit full-on/full-off cycles so CYCLES greater than one produces physical valve edges.
- 2026-05-23: Capped `logs/dod_system.log` to the newest 1000 lines through the central logger service.
- 2026-05-23: Aligned Python valve command builders and docs with the custom `valve_pulse`-backed Klipper macros, including `PRE_FIRE_WAIT` and `POST_FIRE_WAIT` in spotting `SHOOT` commands.
- 2026-05-23: Raised the valve `on_ms` schema minimum to 2.0 ms to match the current `valve_pulse valve_0` macro minimum.
- 2026-05-23: Replaced the Klipper `valve_pulse` macro path with a Pi-side Arduino valve bridge, added bridge trigger scripts, and documented Arduino USB port discovery and setup.
- 2026-05-23: Set the valve `off_ms` schema minimum/default to 2.0 ms to match the current Arduino firmware timing clamp.
- 2026-05-23: Corrected Pi Arduino bridge dependency setup to use Debian `python3-serial` or a venv instead of system pip on externally managed Raspberry Pi OS.
- 2026-05-23: Added Windows PowerShell SSH/SCP copy steps for installing Arduino bridge scripts onto the Pi.
- 2026-05-23: Documented the missing Klipper `gcode_shell_command` extension failure and KIAUH install check for Arduino bridge macros.
- 2026-05-23: Documented running the Arduino valve bridge as a systemd boot service and clarified that `SHOOT` G-code should only trigger an already-running bridge.
- 2026-05-24: Removed explicit `ASYNC` valve behavior from the schema, UI, command builder, and Klipper macro; `SHOOT` now uses pre/post waits as the only timing controls around Arduino firing.
- 2026-05-24: Restored `SHOOT X/Y/SPEED_MM_S` for spotting so each spot is sent as one macro call that places the G1 move and Arduino trigger together.
- 2026-05-24: Made the spotting dispatch window explicit as a dynamic per-job cap, `min(total_spots, dispatch_window_spots)`, so 25-spot jobs queue upfront without flooding large jobs.
- 2026-05-24: Replaced blocking Start-path REST toolhead status checks with cached WebSocket toolhead status and a short homing-status wait after start G-code.
- 2026-05-24: Changed the Klipper listener to use cached WebSocket toolhead status when connected and reserve REST polling for fallback status only.
- 2026-05-24: Added Klipper macros and setup docs for starting or restarting the Arduino valve bridge systemd service from Mainsail.
- 2026-05-24: Added Moonraker-connect G-code dispatch and set the default connect command to `START_ARDUINO_VALVE_BRIDGE`.
- 2026-05-24: Changed Arduino bridge service macros to use non-interactive `sudo -n` and documented the required passwordless sudoers rule.
- 2026-05-24: Documented venv-based Arduino bridge service ExecStart and improved the bridge pyserial error message.
- 2026-05-24: Reverted the Arduino valve firing path to always send the original `O/P/K` serial sequence and removed newer `B`/`X` command assumptions.
- 2026-05-24: Raised the default bounded spotting lookahead cap to 25 so small grids queue upfront while large jobs remain capped.
- 2026-05-24: Raised the default bounded spotting lookahead cap to 500, batched MCU lookahead dispatch into multi-line Moonraker requests, ignored stale `SPOTTER_SHOOT_DONE` GUI messages, and made log trimming non-fatal during high-rate spotting.
- 2026-05-24: Changed spotting progress and dynamic lookahead refill experiments around `arduino_valve_fire` responses and documented that unconditional `M400` would force stop-at-each-spot motion.
- 2026-05-24: Added Pi host-MCU Arduino trigger mode with D2 edge-trigger firmware support, bridge timing preload via `O/P/C`, `SET_ARDUINO_VALVE_TIMING`, and bounded lookahead refill for MCU-triggered spotting.
- 2026-05-24: Armed the Arduino D2 edge-trigger path only after `SET_ARDUINO_VALVE_TIMING` preload so boot-time pin noise no longer fires the valve on startup.
- 2026-05-24: Made the Klipper `SHOOT` macro self-preload Arduino timing in MCU trigger mode so manual macro shots arm the Arduino before toggling the trigger edge.
- 2026-05-24: Changed the GUI `SHOOT` macro default to the USB bridge path for visible console responses, while keeping the MCU GPIO trigger path explicit via `TRIGGER_MODE=mcu`.
- 2026-05-24: Replaced the USB `M400` wait with a Pi-side position-tolerance poll in `arduino_valve_fire.py`, threaded `spot_position_tolerance_mm` through config and command generation, and documented the local wait path.
- 2026-05-24: Tightened the Pi-side USB wait helper to project `motion_report.live_velocity` between updates and derive a faster sample interval from the requested tolerance for high-speed shots.
- 2026-05-24: Raised the USB `arduino_valve_fire` shell timeout to 10 seconds so the local position wait can complete on longer move-and-fire tests.
- 2026-05-24: Rejected macro-response completion for queued MCU spotting after logs showed `SPOTTER_SHOOT_DONE` was emitted during macro expansion; MCU canvas completion and dynamic refill now follow realtime `motion_report.live_position`.
- 2026-05-24: Reset completed canvas spots at run start and made MCU position completion sequence-ordered so stale start positions or reverse travel cannot complete the first dispatch window.
- 2026-05-24: Added timestamped gantry position samples and planned-path projection for MCU spotting completion so sparse live-position updates can refill the dynamic lookahead after the first dispatch window.
- 2026-05-24: Switched the Pi-side wait helper to `motion_report.live_position` so the USB fallback follows realtime motion instead of the queued toolhead target.
- 2026-05-24: Moved USB SHOOT dispatch out of the live macro path into a delayed G-code request so motion can keep queueing while the Pi helper waits on realtime position.
- 2026-05-24: Subscribed the Moonraker websocket client to `motion_report` live position updates and taught the Klipper cache to accept realtime motion-report coordinates as well as toolhead positions.
- 2026-05-24: Removed the delayed USB shell-command path from continuous `SHOOT`; MCU trigger mode now preloads timing once and each spot queues only the move plus `SET_PIN` edge.
- 2026-05-24: Changed GUI MCU-mode `SHOOT` commands to omit `ON_MS`, `OFF_MS`, and `CYCLES` so `SET_ARDUINO_VALVE_TIMING` is the only timing source for continuous runs.
- 2026-05-24: Added a per-`SHOOT` Moonraker response-id completion path during MCU spotting; this is retained only as an explicit fallback and is not the current default.
- 2026-05-24: Updated canvas spot item keys to match grid/row/column-aware spotting progress keys so completed spots recolor during command-response completion.
- 2026-05-24: Changed `SHOOT` to wait for each move to complete before firing so spot execution is move, shoot, then next move.
- 2026-05-24: Reduced spotting lookahead to a 50-spot cap with 25-line dispatch batches and changed active Stop/Close to request Moonraker emergency stop while clearing pending local scripts.
- 2026-05-24: Reverted active Stop/Close to a soft stop, reduced normal lookahead to a 25-spot cap with 5-line batches, and kept Moonraker emergency stop reserved for true emergency shutdown.
- 2026-05-25: Added second-valve MCU trigger support with Arduino D14/D19 trigger inputs, D7/D6 valve outputs, Pi GPIO17/GPIO27 Klipper trigger pins, and per-valve USB timing preload.
- 2026-05-25: Moved the two-valve Arduino trigger inputs from polled D14/D19 pins to interrupt-capable D2/D3 while keeping Pi GPIO17/GPIO27 and D7/D6 valve outputs.
- 2026-05-25: Hardened the two-valve trigger path by removing Arduino INPUT_PULLUP from D2/D3 trigger inputs.
- 2026-05-26: Changed Klipper MCU trigger macros back to deterministic per-valve toggle edges, removed delayed-gcode trigger resets, added Arduino stable-level validation for CHANGE interrupts, and made the GUI manual fire action preload timing before MCU-mode shots.
- 2026-05-26: Removed grid editing and grid-update emission from the machine configuration popup so main-window grid edits are not overwritten by machine-config saves.
- 2026-05-21: Removed upper timing caps from valve timing schema and Klipper validation so timing fields only enforce minimums in the GUI and macros.
- 2026-05-21: Changed async valve firing to use an explicit timed on/off pulse so the valve turns off after `ON_MS` instead of waiting for the next queued motion to finish.
- 2026-05-21: Added sync pre_fire_wait and post_fire_wait support to valve configuration, manual valve firing, and the SHOOT macro so stationary shots can settle before and after firing without changing the async planner flow.
- 2026-05-20: Unified spotting around a single SHOOT payload that always includes X/Y, while Klipper now treats ASYNC shots as fire-only and sync shots as move-then-fire so the app no longer needs separate SHOOT command shapes.
- 2026-05-20: Made spotting progress tracking resilient to missed gantry polls so the bounded dispatch window can advance past already-completed queued spots instead of stalling at the initial 3-command burst.
- 2026-05-20: Logged the Moonraker send_gcode response payload in the dod_system log for both websocket and REST paths so spotting and macro dispatches leave the actual process reply in the trace.
- 2026-05-20: Routed Moonraker REST and WebSocket debug output through the rotating dod_system log, added a plain-language start-to-finish flow guide, reused the main Moonraker connection for spotting, reduced heavy status polling during Start, added explicit shutdown cleanup for Moonraker subscriptions, deferred Moonraker connection until after the UI is shown, added GUI-edited start/end G-code scripts stored in `config/machine_config.json`, and moved the start-script execution ahead of homing validation.
- 2026-05-20: Start, Pause, and Stop controls are disabled until Moonraker connection_status_changed reports connected.
- 2026-05-20: Disabled or unavailable controls now use a light-red style so unusable actions are visually obvious.
- 2026-05-20: Klipper thread progress now emits on the active AppSignals instance so gantry updates refill the bounded spotting dispatch window.
- 2026-05-19: Filtered grid valve selectors to active valves only and refreshed the grid panel valve list after config saves.
- 2026-05-19: Fixed the canvas refresh path so grid updates redraw the background grid layer as well as spot items.
- 2026-05-19: Added an Active checkbox to each grid tab and made the spotting planner ignore inactive grids.
- 2026-05-19: Added editable grid names to the grid tabs and kept tab labels synced to the stored names without renumbering surviving grids.
- 2026-05-19: Allowed grids to be removed down to zero and reset the stale default grid state; empty grid panels now render a clear empty state.
- 2026-05-19: Moved grid valve assignment into each grid tab and removed the standalone assignment button/dialog.
- 2026-05-19: Set explicit canvas z-order so grid visuals render above the background matrix grid.
- 2026-05-19: Switched the Klipper service to the unified SHOOT macro and centralized the command parameter list in code.
- 2026-05-19: Added synced spotting dispatch for valves with async off by sending `SHOOT X=... Y=...` so Klipper moves and fires in one macro call.
- 2026-05-20: Added a preflight homing check for spotting so the app aborts before sending synced commands if X/Y are not homed.
- 2026-05-20: Removed travel-time pacing from spotting dispatch and switched progress updates to live gantry position tracking.
- 2026-05-20: Switched spotting dispatch to a bounded rolling lookahead window so only the next few moves are sent to Klipper at once.
- 2026-05-20: Made spotting fail fast on Moonraker/Klippy disconnects so queued jobs do not hang waiting for completions that will never arrive.
- 2026-05-19: Removed the standalone valve control bar and moved fire actions into each valve's machine-config tab.
- 2026-05-19: Split the machine configuration Valves tab into per-valve sub-tabs and removed pulse-width handling from valve config, command builders, and default valve data.
- 2026-05-19: Removed `CalibrationManager` from the model layer and tests; calibration workflow is now documented as a TODO instead of shipping broken imports.
- 2026-05-19: Removed simulation mode from the spotting controls and worker; spotting now always targets connected hardware and the progress bar reflects completed live spots.
- 2026-05-17: Documentation set reduced and simplified. Added AGENTS.md and removed stale status/snapshot docs.
- 2026-05-17: Normalized style and formatting across remaining human docs for consistent headings, references, and command sections.
- 2026-05-17: Replaced macros.cfg with valve_macros.cfg in docs/klipper_configs, removed separate mcu snippet usage, and aligned references with printer.cfg as source for MCU configuration.
- 2026-05-17: Added optional HTTP `headers` and `route_prefix` support to `services/klipper_service.py` and `services/moonraker_websocket.py`; updated `docs/GUI_INTEGRATION.md` to document auth and routing; removed uploaded `moonraker_mainsail.conf` after validation.
- 2026-05-17: Added latched valve control macros (`VALVE_SET`, `VALVE_ON`, `VALVE_OFF`) and a hold mode to `SHOOT` so valves can stay on permanently without a pulse limit; documented the new commands in `docs/klipper_configs/README.md`.
- 2026-05-18: Grid spot execution now sends `SHOOT` with valve parameters from `config/valve.config.json`; the valve UI and machine config editor expose async/hold/on/off/cycles fields for the shoot command.
- 2026-05-18: Removed the redundant pulse-width slider from the valve panel; the valve config fields now provide the only SHOOT parameter inputs in the GUI.

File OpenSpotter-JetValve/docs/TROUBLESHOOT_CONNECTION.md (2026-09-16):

# Connection Troubleshooting

Use this order to debug connection issues.

## 1. Verify Config

Check [config/machine_config.json](../config/machine_config.json):
- host must be the Pi IP (not localhost)
- port should be 7125 unless customized

## 2. Verify Services On Pi

```bash
sudo systemctl status moonraker
sudo systemctl status klipper
```

## 3. Verify Network Reachability

```powershell
ping <PI_IP>
Invoke-WebRequest -Uri "http://<PI_IP>:7125/api/server/info"
```

## 4. Verify USB MCU Readiness

```bash
tail -f ~/printer_data/logs/klippy.log
```

Look for: `MCU 'mcu' is ready`

## 5. Verify Macro Path

From GUI, send a known macro and observe logs.

## Common Causes

- wrong Pi IP in config
- Moonraker not running
- Klipper not running
- firewall blocking 7125
- invalid printer.cfg macro definitions

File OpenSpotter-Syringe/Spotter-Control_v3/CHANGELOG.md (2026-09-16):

# Changelog

Notable user-visible changes are recorded here. This project follows Semantic
Versioning for the desktop package and keeps data-schema and firmware-contract
versions separate.

## [Unreleased]

### Added

- A versioned pattern plugin API with validated manifests, deterministic
  built-in discovery, installed `openspotter.patterns` entry points,
  idempotent loading, compatibility checks, and duplicate-ID protection.
- A full application-plugin contract covering workspace metadata, editor
  creation, defaults, profiles, saved generation, strict direct-run capture,
  worker generation, workflow field groups, and visual bindings.
- Separate built-in `app.plugins.grid` and `app.plugins.spiral` packages with
  owned manifests, fields, editors, planners, generation, runtime adapters,
  canvas previews, workflow metadata, and representative workflow previews.
- Typed workflow contributions for plugin-owned field groups, triggers,
  trigger/job scopes, derived variables, context defaults, and required custom
  values, with deterministic conflict detection.
- Optional `WorkflowPreviewPlugin` dispatch so plugins can provide realistic
  representative event values without teaching the workflow editor their
  semantics.
- Optional `CanvasPreviewProvider` support with detached preview context/style,
  immutable marker/polyline/line primitives, hidden safety points, warnings,
  metadata, z-order, and per-primitive acceptance relevance.
- Generic immutable `PatternRecipeSnapshot` and
  `RuntimeGenerationContext` models plus shared strict runtime field, range,
  container, and text validators.
- Schema-version 3 generation profiles with a generic `patterns` array,
  plugin IDs/versions, canonical recipes, and portable G-code filenames.
- Schema-version 2 workspace state with a generic registered-plugin count map.
- Reusable core packages for schemas, schema-driven Tk forms, atomic storage,
  domain/geometry helpers, canvas models, workflow composition, and shared
  G-code lifecycle/profile services.
- PEP 621 package metadata, `openspotter-control` and `python -m app`
  entry points, package data declarations, and Semantic/PEP 440 version
  metadata.
- Source, per-user, portable, and explicit runtime-storage modes; first-run
  default seeding; and opt-in migration from an earlier checkout.
- A PyInstaller standalone-build specification and deployment/release
  documentation for source, wheel, and frozen installations.
- Windows and Ubuntu CI across Python 3.8 and 3.12, including compilation,
  the full test suite, wheel building, and an installed-wheel smoke test
  outside the checkout.
- Architecture-boundary tests that prevent core-to-concrete/shell imports,
  outward dependencies in pure plugin layers, and duplicate implementations in
  legacy facades.
- Contributor, architecture, plugin-development, deployment, versioning, and
  release documentation plus repository text/binary normalization rules.

### Changed

- The main window now builds workspaces, mode selection, add/remove actions,
  state restoration, defaults, profile loading, workflow values, and visual
  bindings from registered application plugins.
- Top-level saved generation now dispatches every non-empty application plugin
  and derives output suffixes from stable plugin IDs.
- Direct Start now delegates strict Tk-thread recipe capture and detached worker
  generation to the selected plugin. Shared runtime code validates ownership,
  total work, artifact size, hashing, line indexing, retention, and remote
  naming without pattern branches.
- Machine confirmation now uses manifest display metadata and generic recipe
  counts while retaining the exact workflow hash, artifact SHA-256, size, line
  count, destination, fresh preflight, upload-without-start, and separate start
  RPC.
- Canvas collection and drawing now combine renderer-neutral results from every
  preview-capable plugin. Fit-to-content, acceptance checking, stable z-order,
  and provider-failure isolation are shell-owned and pattern-neutral.
- Workflow validation/catalog/defaults now aggregate core and registered plugin
  contributions; detailed event previews dispatch optional plugin enrichers.
- The active workflow path now resolves to writable runtime configuration,
  while a separate immutable shipped path is used only as the missing-file
  fallback.
- The field schema now supports widget and choice hints. Global and plugin
  editors share one form builder, including readonly spiral mode/interleave
  choices.
- The legacy `max_grid_count` value is presented and enforced as **Maximum
  Pattern Count** for every registered workspace.
- Grid and spiral field, planning, generation, preview, runtime, and workflow
  ownership moved out of mixed top-level modules into their plugin packages.
- Atomic JSON/text replacement is shared by defaults, state, workflow,
  profiles, visual objects, and local Moonraker settings.
- Packaged application resources are separated from writable operator data;
  installed/frozen applications no longer attempt to mutate package files.
- Resource/config/output/log paths no longer depend on the current working
  directory.
- Local Moonraker credentials remain per-user runtime data, are excluded from
  package artifacts, and retain owner-only permission hardening where the
  platform supports it.

### Compatibility

- `app.grid`, `app.spiral_grid`, `app.grid_gcode`, `app.spiral_gcode`,
  `app.gcode_planner`, and `app.SpotterFunctions` remain export-only
  compatibility facades while new code imports the owning core or plugin
  module. `app.input_configs` retains global fields and compatibility-exports
  plugin-owned fields.
- Built-in schema-version 3 profiles retain `grid_settings` and
  `spiral_settings` arrays for schema-version 2 readers.
- Profile loading accepts generic schema-version 3 patterns and legacy
  per-plugin arrays.
- Workspace state writes the generic schema-version 2 `patterns` mapping plus
  legacy plugin count keys and still reads the shipped unversioned built-in
  state seed.
- `GenerationSnapshot.grids`/`.spirals`, built-in GUI helper names, and
  grid-like editor naming aliases remain available while generic code uses
  plugin-tagged recipes and neutral methods.

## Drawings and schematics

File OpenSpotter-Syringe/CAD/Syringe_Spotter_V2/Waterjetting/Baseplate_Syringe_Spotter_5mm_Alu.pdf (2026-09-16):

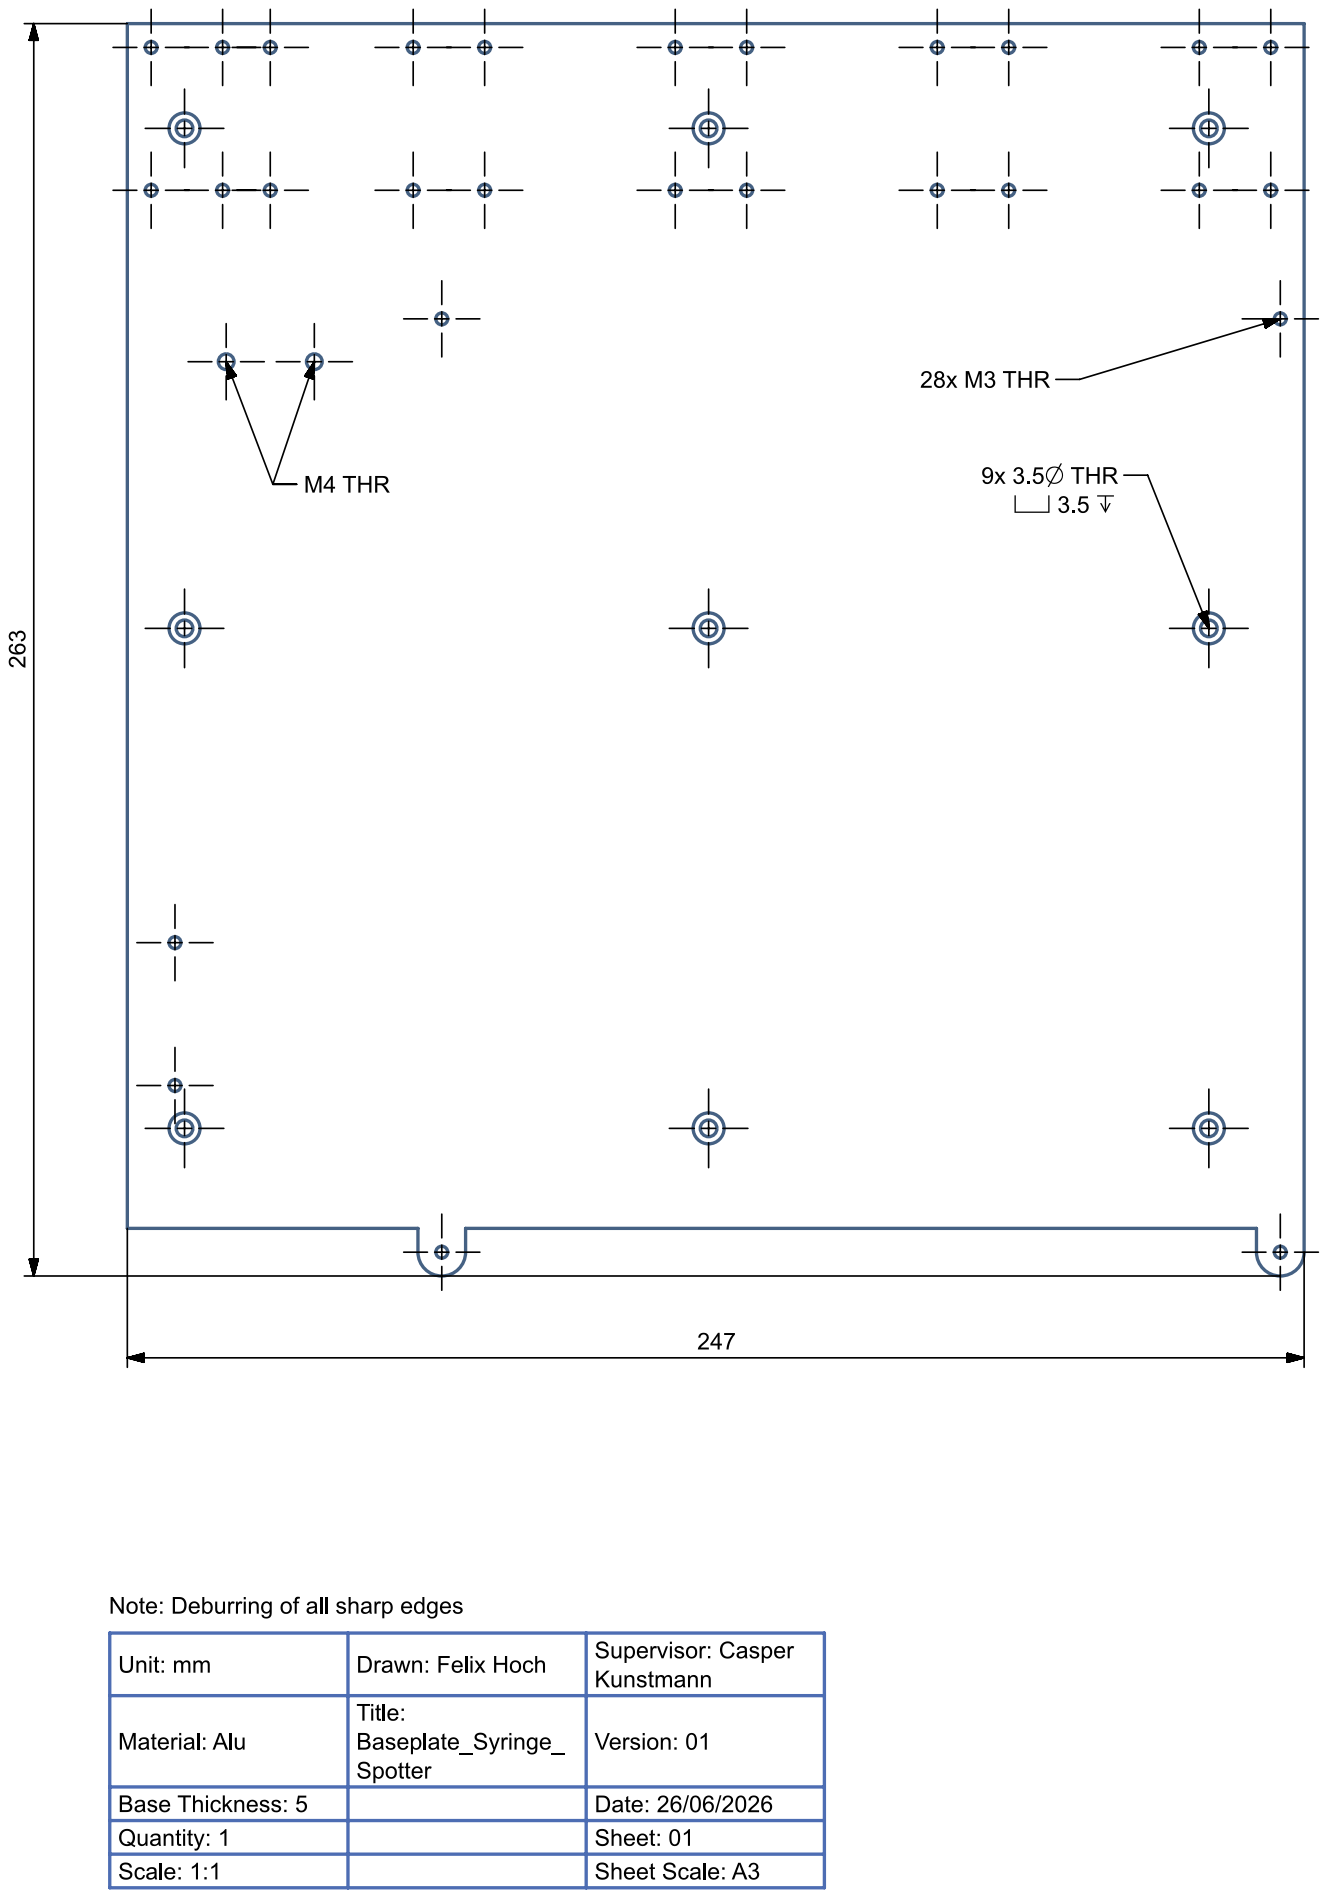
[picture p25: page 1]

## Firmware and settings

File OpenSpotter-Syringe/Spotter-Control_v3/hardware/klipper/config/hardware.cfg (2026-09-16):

# =============================================================================
# Hardware Configuration - Stepper Motors + Servo
# Einsy RAMBo 1.2b Pin Assignments
# =============================================================================


# =============================================================================
# X AXIS
# =============================================================================
[stepper_x]
step_pin: PC0
dir_pin: !PL0
enable_pin: !PA7
microsteps: 16
rotation_distance: 32

# Sensorless homing via TMC2130 X-DIAG
endstop_pin: tmc2130_stepper_x:virtual_endstop

position_endstop: -32
position_min: -33
position_max: 215

homing_speed: 40
homing_retract_dist: 3

# =============================================================================
# TMC2130 Y
# =============================================================================
[tmc2130 stepper_y]
cs_pin: PG2
interpolate: True
run_current: 0.500
sense_resistor: 0.220
diag1_pin: !PK7

driver_iholddelay: 8
driver_tpowerdown: 0
driver_tbl: 2
driver_toff: 3
driver_hend: 1
driver_hstrt: 5
driver_pwm_freq: 2
driver_pwm_grad: 2
driver_pwm_ampl: 230
driver_pwm_autoscale: True

# Sensorless homing sensitivity.
# Increase if it hits the frame without triggering.
# Decrease if it false-triggers before reaching the end.
driver_sgt: 10


# =============================================================================
# Y AXIS
# =============================================================================
[stepper_y]
step_pin: PC1
dir_pin: !PL1
enable_pin: !PA6
microsteps: 16
rotation_distance: 32

# Sensorless homing via TMC2130 Y-DIAG
endstop_pin: tmc2130_stepper_y:virtual_endstop

position_endstop: -42
position_min: -43
position_max: 160

homing_speed: 40
homing_retract_dist: 3

# =============================================================================
# TMC2130 X
# =============================================================================
[tmc2130 stepper_x]
cs_pin: PG0
interpolate: True
run_current: 0.450
sense_resistor: 0.220
diag1_pin: !PK2

driver_iholddelay: 8
driver_tpowerdown: 0
driver_tbl: 2
driver_toff: 3
driver_hend: 1
driver_hstrt: 5
driver_pwm_freq: 2
driver_pwm_grad: 2
driver_pwm_ampl: 230
driver_pwm_autoscale: True

# Sensorless homing sensitivity.
# Increase if it hits the frame without triggering.
# Decrease if it false-triggers before reaching the end.
driver_sgt: 20



# =============================================================================
# Z AXIS
# =============================================================================
[stepper_z]
step_pin: PC2
dir_pin: !PL2
enable_pin: !PA5
microsteps: 16
rotation_distance: 8

# Sensorless homing via TMC2130 Z-DIAG
endstop_pin: tmc2130_stepper_z:virtual_endstop

position_endstop: 95
position_max: 100
position_min: -25

homing_speed: 20
homing_retract_dist: 3

# =============================================================================
# TMC2130 Z
# =============================================================================
[tmc2130 stepper_z]
cs_pin: PK5
run_current: 0.600
sense_resistor: 0.220
diag1_pin: !PK6
interpolate: True

driver_iholddelay: 8
driver_tpowerdown: 0
driver_tbl: 2
driver_toff: 3
driver_hend: 1
driver_hstrt: 5
driver_pwm_freq: 2
driver_pwm_grad: 4
driver_pwm_ampl: 200
driver_pwm_autoscale: True

# Sensorless homing sensitivity.
# Increase if it hits the frame without triggering.
# Decrease if it false-triggers before reaching the end.
driver_sgt: 10


# =============================================================================
# SERVO
# =============================================================================
[servo my_servo]
pin: PJ5
maximum_servo_angle: 180
minimum_pulse_width: 0.0007
maximum_pulse_width: 0.0025
initial_angle: 10

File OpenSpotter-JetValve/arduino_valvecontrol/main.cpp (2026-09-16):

#include <Arduino.h>

const uint8_t VALVE_COUNT = 2;
const uint8_t VALVE_OUTPUT_PINS[VALVE_COUNT] = {7, 6};   // VALVE=0 -> D7, VALVE=1 -> D6
const uint8_t TRIGGER_PINS[VALVE_COUNT] = {2, 3};        // VALVE=0 -> D2/INT0, VALVE=1 -> D3/INT1
const unsigned long TICK_US = 100;                       // 0.1 ms per unit from GUI

// Timing ranges (0.1 ms units)
unsigned long onMinTicks = 20;
unsigned long onMaxTicks = 20000;
unsigned long offMinTicks = 20;
unsigned long offMaxTicks = 20000;

// Derived step sizes for the legacy serial tuning commands.
unsigned long onStepTicks = 1;
unsigned long offStepTicks = 1;

struct ValveState {
  unsigned long onTicks;
  unsigned long offTicks;
  unsigned long triggerCycles;
  bool triggerArmed;
  bool pulseActive;
  bool pulseHighPhase;
  unsigned long pulsePhaseStartUs;
  unsigned long pulsesRemaining;
};

ValveState valves[VALVE_COUNT];
uint8_t selectedValve = 0;
volatile bool triggerRequested[VALVE_COUNT] = {false, false};
bool acceptedTriggerLevel[VALVE_COUNT] = {false, false};

void requestTrigger0() {
  triggerRequested[0] = true;
}

void requestTrigger1() {
  triggerRequested[1] = true;
}

unsigned long clampUnsignedLong(unsigned long v, unsigned long lo, unsigned long hi) {
  if (v < lo) return lo;
  if (v > hi) return hi;
  return v;
}

unsigned long computeStep(unsigned long lo, unsigned long hi) {
  if (hi <= lo) return 1;
  unsigned long span = hi - lo;
  unsigned long step = span / 9;
  if (step == 0) step = 1;
  return step;
}

unsigned long subtractStep(unsigned long value, unsigned long step, unsigned long floorValue) {
  if (value <= floorValue || step >= value - floorValue) {
    return floorValue;
  }
  return value - step;
}

void applyRangeAndClamp() {
  onStepTicks = computeStep(onMinTicks, onMaxTicks);
  offStepTicks = computeStep(offMinTicks, offMaxTicks);
  for (uint8_t valve = 0; valve < VALVE_COUNT; valve++) {
    valves[valve].onTicks = clampUnsignedLong(valves[valve].onTicks, onMinTicks, onMaxTicks);
    valves[valve].offTicks = clampUnsignedLong(valves[valve].offTicks, offMinTicks, offMaxTicks);
  }
}

bool isValidValve(int valve) {
  return valve >= 0 && valve < VALVE_COUNT;
}

String commandPayload(const String &line) {
  if (line.length() > 2 && line.charAt(1) == ':') {
    return line.substring(2);
  }
  if (line.length() > 1) {
    return line.substring(1);
  }
  return "";
}

void handleRangeCommand(const String &payload) {
  int p1 = payload.indexOf(':');
  int p2 = payload.indexOf(':', p1 + 1);
  int p3 = payload.indexOf(':', p2 + 1);
  if (p1 < 0 || p2 < 0 || p3 < 0) {
    Serial.println("ERR bad range format");
    return;
  }

  unsigned long onLo = payload.substring(0, p1).toInt();
  unsigned long onHi = payload.substring(p1 + 1, p2).toInt();
  unsigned long offLo = payload.substring(p2 + 1, p3).toInt();
  unsigned long offHi = payload.substring(p3 + 1).toInt();
  if (onHi <= onLo || offHi <= offLo) {
    Serial.println("ERR range order");
    return;
  }

  onMinTicks = onLo;
  onMaxTicks = onHi;
  offMinTicks = offLo;
  offMaxTicks = offHi;
  applyRangeAndClamp();
}

void startPulses(uint8_t valve, unsigned long count) {
  if (count == 0) {
    Serial.println("ERR pulse count");
    return;
  }

  if (valves[valve].pulseActive) {
    Serial.println("ERR busy");
    return;
  }

  valves[valve].pulsesRemaining = count;
  valves[valve].pulseActive = true;
  valves[valve].pulseHighPhase = true;
  valves[valve].pulsePhaseStartUs = micros();
  digitalWrite(VALVE_OUTPUT_PINS[valve], HIGH);
}

void handleCommand(String line) {
  line.trim();
  if (line.length() == 0) return;

  char cmd = line.charAt(0);
  ValveState &valve = valves[selectedValve];

  switch (cmd) {
    case 'V': {
      int requested = commandPayload(line).toInt();
      if (!isValidValve(requested)) {
        Serial.println("ERR valve");
        break;
      }
      selectedValve = static_cast<uint8_t>(requested);
      break;
    }
    case 'E':
      valve.onTicks = subtractStep(valve.onTicks, onStepTicks, onMinTicks);
      break;
    case 'R':
      valve.onTicks = clampUnsignedLong(valve.onTicks + onStepTicks, onMinTicks, onMaxTicks);
      break;
    case 'D':
      valve.offTicks = subtractStep(valve.offTicks, offStepTicks, offMinTicks);
      break;
    case 'F':
      valve.offTicks = clampUnsignedLong(valve.offTicks + offStepTicks, offMinTicks, offMaxTicks);
      break;
    case 'S':
      handleRangeCommand(commandPayload(line));
      break;
    case 'O':
      valve.onTicks = clampUnsignedLong(commandPayload(line).toInt(), onMinTicks, onMaxTicks);
      break;
    case 'P':
      valve.offTicks = clampUnsignedLong(commandPayload(line).toInt(), offMinTicks, offMaxTicks);
      break;
    case 'K': {
      unsigned long count = commandPayload(line).toInt();
      if (count == 0) {
        count = 1;
      }
      startPulses(selectedValve, count);
      break;
    }
    case 'C': {
      unsigned long requested = commandPayload(line).toInt();
      if (requested == 0) {
        Serial.println("ERR trigger cycles");
        break;
      }
      valve.triggerCycles = requested;
      valve.triggerArmed = true;
      acceptedTriggerLevel[selectedValve] = digitalRead(TRIGGER_PINS[selectedValve]) == HIGH;
      break;
    }
    case '?':
      break;
    default:
      Serial.println("ERR unknown");
      break;
  }
}

void consumeTriggerRequests() {
  for (uint8_t valve = 0; valve < VALVE_COUNT; valve++) {
    noInterrupts();
    bool requested = triggerRequested[valve];
    triggerRequested[valve] = false;
    interrupts();

    if (requested && valves[valve].triggerArmed) {
      bool currentLevel = digitalRead(TRIGGER_PINS[valve]) == HIGH;
      if (currentLevel == acceptedTriggerLevel[valve]) {
        continue;
      }
      acceptedTriggerLevel[valve] = currentLevel;
      startPulses(valve, valves[valve].triggerCycles);
    }
  }
}

void updatePulse(uint8_t valve) {
  ValveState &state = valves[valve];
  if (!state.pulseActive) {
    return;
  }

  unsigned long nowUs = micros();
  if (state.pulseHighPhase) {
    if (nowUs - state.pulsePhaseStartUs >= state.onTicks * TICK_US) {
      state.pulseHighPhase = false;
      state.pulsePhaseStartUs = nowUs;
      digitalWrite(VALVE_OUTPUT_PINS[valve], LOW);
    }
    return;
  }

  if (nowUs - state.pulsePhaseStartUs >= state.offTicks * TICK_US) {
    if (state.pulsesRemaining > 1) {
      state.pulsesRemaining--;
      state.pulseHighPhase = true;
      state.pulsePhaseStartUs = nowUs;
      digitalWrite(VALVE_OUTPUT_PINS[valve], HIGH);
    } else {
      state.pulsesRemaining = 0;
      state.pulseActive = false;
      digitalWrite(VALVE_OUTPUT_PINS[valve], LOW);
    }
  }
}

void setup() {
  for (uint8_t valve = 0; valve < VALVE_COUNT; valve++) {
    pinMode(VALVE_OUTPUT_PINS[valve], OUTPUT);
    digitalWrite(VALVE_OUTPUT_PINS[valve], LOW);
    pinMode(TRIGGER_PINS[valve], INPUT);
    acceptedTriggerLevel[valve] = digitalRead(TRIGGER_PINS[valve]) == HIGH;

    valves[valve].onTicks = 100;
    valves[valve].offTicks = 900;
    valves[valve].triggerCycles = 1;
    valves[valve].triggerArmed = false;
    valves[valve].pulseActive = false;
    valves[valve].pulseHighPhase = false;
    valves[valve].pulsePhaseStartUs = 0;
    valves[valve].pulsesRemaining = 0;
  }

  Serial.begin(9600);
  while (!Serial) { }

  applyRangeAndClamp();
  attachInterrupt(digitalPinToInterrupt(TRIGGER_PINS[0]), requestTrigger0, CHANGE);
  attachInterrupt(digitalPinToInterrupt(TRIGGER_PINS[1]), requestTrigger1, CHANGE);
}

void loop() {
  if (Serial.available()) {
    String line = Serial.readStringUntil('\n');
    handleCommand(line);
  }

  consumeTriggerRequests();

  for (uint8_t valve = 0; valve < VALVE_COUNT; valve++) {
    updatePulse(valve);
  }
}

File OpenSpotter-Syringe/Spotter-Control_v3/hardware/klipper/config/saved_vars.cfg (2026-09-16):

[Variables]
bltouch_parked = False
bltouch_state = 'loaded'
syringe_pos_mm = 50
tcp_expected_x = 40.0
tcp_expected_y = 170.0
tcp_expected_z = -14.0
tcp_offset_x = -8.9875
tcp_offset_y = -0.5125
tcp_offset_z = 6.31640625
tcp_power_on = False
tcp_ready = True
tcp_tip_x = 31.0125
tcp_tip_y = 169.4875
tcp_tip_z = -7.68359375

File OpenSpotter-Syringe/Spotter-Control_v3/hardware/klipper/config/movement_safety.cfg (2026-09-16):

# =============================================================================
# Movement Safety / Dead Zones / Needle Tip Offsets
# =============================================================================
# Normal G0/G1 moves are routed through this guard. When needle tip offsets are
# enabled, absolute XYZ move targets are interpreted as needle-tip coordinates:
# saved tcp_offset_x/y/z are added to the commanded axes and the live
# needle_surface_z_offset is added to Z. Relative moves remain relative deltas.
#
# Dead zones are stored dynamically in save_variables as movement_dead_zones.
# Their bounds are machine/physical coordinates.  The guard converts absolute
# logical G-code targets into that physical frame before testing a path.
# The guard loops over however many saved zones exist:
#   []                         -> no zone checks
#   [{'name':'zone1', ...}]    -> check one zone
#   [{'name':'zone1', ...},
#    {'name':'zone2', ...}]    -> check both zones
#
# Each zone is an XY rectangle with independent movement rules:
#   allow_when_above: allow any move touching the zone if both start and target
#                     Z are at/above z_clearance.
#   allow_exit:       allow XY moves from inside the zone to outside.
#   allow_z_lift:     allow pure Z-up moves while inside the zone.
#   allow_z_lower:    allow pure Z-down moves while inside the zone.
#   allow_xy_inside:  allow XY moves that start and end inside the zone.
#
# Conservative path check:
#   If a move's XY bounding box overlaps a zone, the move is treated as touching
#   that zone. This is intentionally stricter than exact line intersection.
#
# Example:
#   SET_DEAD_ZONE NAME=fixture X_MIN=80 X_MAX=170 Y_MIN=60 Y_MAX=160 Z_CLEARANCE=20 ALLOW_WHEN_ABOVE=1 ALLOW_EXIT=1 ALLOW_Z_LIFT=1
#   MOVEMENT_SAFETY_ENABLE
#
# Needle tip offset workflow:
#   TCPCALIBRATE / TCPSTART saves tcp_offset_x/y/z, the coordinate version,
#   and tcp_ready=True.
#   NEEDLE_TIP_OFFSETS_ENABLE
#   SET_NEEDLE_SURFACE_OFFSET Z=-0.030 MOVE=1 SAVE=1
#   NEEDLE_TIP_OFFSETS_DISABLE
# A UI slider can repeatedly send SET_NEEDLE_SURFACE_OFFSET with MOVE=1.
# Negative surface Z moves the needle closer to the substrate.
# =============================================================================

[gcode_macro _NEEDLE_TIP_OFFSETS]
description: Runtime defaults for applying saved TCP offsets plus live needle Z trim to normal G0/G1 moves
variable_enabled: 0
variable_require_tcp_ready: 1
variable_surface_z: 0.0
variable_min_surface_z: -2.0
variable_max_surface_z: 2.0
gcode:
    NEEDLE_TIP_OFFSETS_STATUS

[delayed_gcode NEEDLE_TIP_OFFSETS_INIT]
initial_duration: 1.0
gcode:
    {% set svv = printer.save_variables.variables %}
    {% set saved_surface_z = svv.needle_surface_z_offset|default(0.0)|float %}
    SET_GCODE_VARIABLE MACRO=_NEEDLE_TIP_OFFSETS VARIABLE=surface_z VALUE={saved_surface_z}

[gcode_macro NEEDLE_TIP_OFFSETS_ENABLE]
description: Enable saved TCP XYZ offsets plus live needle Z trim for normal G0/G1 moves
gcode:
    {% set cfg = printer['gcode_macro _NEEDLE_TIP_OFFSETS'] %}
    {% set svv = printer.save_variables.variables %}
    {% set require_tcp = params.REQUIRE_TCP|default(cfg.require_tcp_ready)|int %}
    {% if require_tcp == 1 and svv.tcp_ready|default(false) != true %}
        {action_raise_error("Needle tip offsets blocked: saved TCP calibration is not ready (tcp_ready=" ~ svv.tcp_ready|default(false) ~ "). Run TCPSTART/TCPCALIBRATE first, or use NEEDLE_TIP_OFFSETS_ENABLE REQUIRE_TCP=0 for a dry run.")}
    {% endif %}
    SET_GCODE_VARIABLE MACRO=_NEEDLE_TIP_OFFSETS VARIABLE=enabled VALUE=1
    RESPOND MSG="Needle tip offsets enabled: tcp X={svv.tcp_offset_x|default(0.0)} Y={svv.tcp_offset_y|default(0.0)} Z={svv.tcp_offset_z|default(0.0)}, live surface Z={cfg.surface_z|float|round(4)}"

[gcode_macro NEEDLE_TIP_OFFSETS_DISABLE]
description: Disable TCP/live needle offsets for normal G0/G1 moves
gcode:
    SET_GCODE_VARIABLE MACRO=_NEEDLE_TIP_OFFSETS VARIABLE=enabled VALUE=0
    RESPOND MSG="Needle tip offsets disabled"

[gcode_macro NEEDLE_TIP_OFFSETS_STATUS]
description: Report TCP offsets and live needle surface Z trim
gcode:
    {% set cfg = printer['gcode_macro _NEEDLE_TIP_OFFSETS'] %}
    {% set svv = printer.save_variables.variables %}
    {% set tcp_x = svv.tcp_offset_x|default(0.0)|float %}
    {% set tcp_y = svv.tcp_offset_y|default(0.0)|float %}
    {% set tcp_z = svv.tcp_offset_z|default(0.0)|float %}
    {% set surface_z = cfg.surface_z|float %}
    RESPOND MSG="Needle offsets enabled={cfg.enabled|int}; tcp_ready={svv.tcp_ready|default(false)}; TCP X={tcp_x|round(4)} Y={tcp_y|round(4)} Z={tcp_z|round(4)}; live surface Z={surface_z|round(4)}; total Z add={(tcp_z + surface_z)|round(4)}"

[gcode_macro SET_NEEDLE_SURFACE_OFFSET]
description: Set live needle-to-surface Z trim. Args: Z MOVE=0|1 SAVE=0|1 F=<feedrate>
gcode:
    {% if params.Z is not defined %}
        {action_raise_error("SET_NEEDLE_SURFACE_OFFSET requires Z=<offset_mm>")}
    {% endif %}
    {% set cfg = printer['gcode_macro _NEEDLE_TIP_OFFSETS'] %}
    {% set old_z = cfg.surface_z|float %}
    {% set new_z = params.Z|float %}
    {% set min_z = cfg.min_surface_z|float %}
    {% set max_z = cfg.max_surface_z|float %}
    {% set move = params.MOVE|default(0)|int %}
    {% set save = params.SAVE|default(0)|int %}
    {% set feed = params.F|default(300)|float %}
    {% set position = printer.toolhead.position %}
    {% set gcode_position = printer.gcode_move.gcode_position %}
    {% set absolute = printer.gcode_move.absolute_coordinates %}
    {% set axis_minimum = printer.toolhead.axis_minimum %}
    {% set axis_maximum = printer.toolhead.axis_maximum %}
    {% if not (new_z >= min_z and new_z <= max_z) %}
        {action_raise_error("Needle surface offset must be finite and inside allowed range [" ~ min_z ~ ", " ~ max_z ~ "] mm")}
    {% endif %}
    {% if not (feed >= 1.0 and feed <= 1500.0) %}
        {action_raise_error("Needle surface offset feed must be finite and between 1 and 1500 mm/min")}
    {% endif %}
    {% if not (old_z >= min_z and old_z <= max_z) and move == 1 %}
        {action_raise_error("Existing live needle Z is invalid; recover with SET_NEEDLE_SURFACE_OFFSET Z=0 MOVE=0 SAVE=0 before requesting motion")}
    {% endif %}
    {% set delta = new_z - old_z %}
    {% set target_z = position.z|float + delta %}
    {% if move == 1 and cfg.enabled|int == 1 and delta|abs > 0.000001 %}
        {% if not (target_z >= axis_minimum.z|float and target_z <= axis_maximum.z|float) %}
            {action_raise_error("Live needle Z target is outside the configured toolhead limits")}
        {% endif %}
        _CHECK_MOVE_SAFETY Z={gcode_position.z|float + delta if absolute else delta}
        SAVE_GCODE_STATE NAME=_needle_surface_offset_live
        G0.1 Z{gcode_position.z|float + delta if absolute else delta} F{feed}
        M400
        RESTORE_GCODE_STATE NAME=_needle_surface_offset_live
    {% endif %}
    SET_GCODE_VARIABLE MACRO=_NEEDLE_TIP_OFFSETS VARIABLE=surface_z VALUE={new_z}
    {% if save == 1 %}
        SAVE_VARIABLE VARIABLE=needle_surface_z_offset VALUE={new_z}
    {% endif %}
    RESPOND MSG="Needle surface Z offset set to {new_z|round(4)} mm; delta={delta|round(4)} mm; enabled={cfg.enabled|int}"

[gcode_macro ADJUST_NEEDLE_SURFACE_OFFSET]
description: Increment live needle-to-surface Z trim. Args: Z_ADJUST=<delta_mm> MOVE=0|1 SAVE=0|1 F=<feedrate>
gcode:
    {% if params.Z_ADJUST is not defined and params.Z is not defined %}
        {action_raise_error("ADJUST_NEEDLE_SURFACE_OFFSET requires Z_ADJUST=<delta_mm>")}
    {% endif %}
    {% set cfg = printer['gcode_macro _NEEDLE_TIP_OFFSETS'] %}
    {% set adjust = params.Z_ADJUST|default(params.Z)|float %}
    {% set new_z = cfg.surface_z|float + adjust %}
    SET_NEEDLE_SURFACE_OFFSET Z={new_z} MOVE={params.MOVE|default(0)|int} SAVE={params.SAVE|default(0)|int}{% if params.F is defined %} F={params.F}{% endif %}

[gcode_macro RESET_NEEDLE_SURFACE_OFFSET]
description: Reset live needle-to-surface Z trim to zero. Args: MOVE=0|1 SAVE=0|1 F=<feedrate>
gcode:
    SET_NEEDLE_SURFACE_OFFSET Z=0 MOVE={params.MOVE|default(0)|int} SAVE={params.SAVE|default(0)|int}{% if params.F is defined %} F={params.F}{% endif %}

[gcode_macro _MOVEMENT_SAFETY]
description: Runtime defaults for G0/G1 dead-zone crash protection
variable_enabled: 0
gcode:
    MOVEMENT_SAFETY_STATUS

[gcode_macro MOVEMENT_SAFETY_ENABLE]
description: Enable G0/G1 dead-zone checks
gcode:
    SET_GCODE_VARIABLE MACRO=_MOVEMENT_SAFETY VARIABLE=enabled VALUE=1
    SAVE_VARIABLE VARIABLE=movement_safety_enabled VALUE=1
    RESPOND MSG="Movement safety enabled"

[gcode_macro MOVEMENT_SAFETY_DISABLE]
description: Disable G0/G1 dead-zone checks
gcode:
    SET_GCODE_VARIABLE MACRO=_MOVEMENT_SAFETY VARIABLE=enabled VALUE=0
    SAVE_VARIABLE VARIABLE=movement_safety_enabled VALUE=0
    RESPOND MSG="Movement safety disabled"
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

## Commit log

2024-06-21 First Upload to git
    [config.txt]
2024-06-21 basic movement
    [config.txt]
2024-07-10 tatiana calibration
    added tatianas config files and movement speeds in gui
    [config_tatiana.txt]
2024-07-10 refactoring
    refactoring step one, function adding
    [config.txt, config_tatiana.txt]
2024-07-14 created new gui
    new gui with better implementation of classes and objects. new grids can now be easily added, called and customized
    [config_global.txt, config_grid_1.txt, config_grid_2.txt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]
2024-07-14 code creation implemented
    new gui can produce gcode and is ready for lab testing
    [config_grid_2.txt]
2024-07-15 test of refactored code succesful
    tested new code in lab, no water test but all functions seem functional
    [config_global.txt, config_grid_1.txt, config_grid_2.txt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]
2025-12-03 working life droplet feedback
    [config_global.txt, config_grid_1.txt, config_grid_2.txt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]
2025-12-18 rady for testing
    [TPU_Oring_100mmChuck.prt]
2025-12-19 reagy for calibration
2026-01-05 mesh bed leveling
2026-01-05 zoom canvas, printer bed
2026-01-06 working big chuck grid tested
    [config_global.txt, config_grid_1.txt, config_grid_2.txt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]
2026-03-03 klipper impl, missing syring features
2026-03-05 gcdoe to mainsail
    [mainsail.cfg]
2026-03-08 first successful klipper dry run , single grid
    [syring.cfg]
2026-04-30 grid parameters for adrei printing & software upgrades
    [d4_5%_1_3_thf_chn_2_grid_second_parameters_settings.txt, d4_5%_1_3_thf_chn_5_grid_third_parameters_settings.txt, d4_5%_1_3_thf_chn_9_grid_second_parameters_set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]
2026-06-09 spiral testing and klipper docs copy
    [bed_mesh.cfg, bltouch.cfg, display.cfg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]
2026-06-18 cleanup & documentation
    [bed_mesh.cfg, bltouch.cfg, d4_5%_1_3_thf_chn_2_grid_second_parameters_settings.txt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]
2026-06-23 Rename project in README
    Updated project name in README from OpenSpotter-Syringe to OpenSpotter-Hub.
2026-06-26 move to labn
    [0ASM_Syringe_Spotter_SDU_V2.prt, Assembly Micro Servo MG90S_step.prt, BLtouch_ToolStation_SDU_V2.prt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]
2026-06-26 printing and v2 spotter dev
    [0ASM_Syringe_Spotter_SDU_V2.prt, BLtouch_ToolStation1_SDU_V2.stl, BLtouch_ToolStation2_SDU_V2.stl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]
2026-06-26 bltouch error fix
    [0ASM_Syringe_Spotter_SDU_V2.prt, BLtouch_ToolStation2_SDU_V2.stl, BLtouch_ToolStation_SDU_V2.prt]
2026-06-30 V2 DEV POR BLOCK & baseplate & servo lid
    [0ASM_Syringe_Spotter_SDU_V2.prt, BLtouch_ToolStation2_SDU_V2.stl, BLtouch_ToolStation_SDU_V2.prt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]
2026-07-02 baseplate drawings
    [0ASM_Syringe_Spotter_SDU_V2.prt, Baseplate_SDU_V2.prt, Baseplate_Syringe_Spotter_5mm_Alu.dxf]
2026-07-08 optocoupler housing
    [0ASM_Syringe_Spotter_SDU_V2.prt, TCP_OPTOCOUPLER_Housing.prt, TCP_OPTOCOUPLER_Housing.stl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]
2026-07-09 klipper source & tcp code
    [bed_mesh.cfg, bed_screws.cfg, bltouch.cfg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]
2026-07-10 tcp implementation
    [display.cfg, tcp_calibration.cfg]
2026-07-16 rewrite commit one, theme, dynamic cooding, linked vars
    [bed_mesh.cfg, bed_screws.cfg, bltouch.cfg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]
2026-07-16 rewrite commit one
    [Syringe_10uL_SDU_V2.prt, bltouch.cfg, hardware.cfg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]
2026-07-16 feat: add machine control workflow and hardware updates
    [0ASM_Syringe_Spotter_SDU_V2.prt, BLtouch_ToolStation_SDU_V2.prt, Baseplate_SDU_V2.prt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]
2026-07-17 remote refactor
    [hardware.cfg, mainsails.cfg, printer.cfg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]
2026-07-19 feat(syringe): update machine workflow and hardware calibration
    Checkpoint all ongoing application, workflow, Klipper, documentation, test, and hardware-image changes. Hardware commissioning and resolution of the currently failing unit tests remain in progress.
    [bltouch.cfg, hardware.cfg, mainsail.cfg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]
2026-09-16 adding of jetvalve files
    [machine_config.json, mainsail.cfg, printer.cfg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]
2026-10-28 Bump aiohttp in /OpenSpotter-Syringe/Spotter-Control_v3
    ---
    updated-dependencies:
    - dependency-name: aiohttp
    dependency-version: 3.14.4
    dependency-type: direct:production
    ...
